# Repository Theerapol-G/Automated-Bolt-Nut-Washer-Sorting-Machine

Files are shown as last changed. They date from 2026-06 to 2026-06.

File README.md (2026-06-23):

# NBN Sorter - Automated Bolt, Nut \& Washer Sorting Machine



> A mechatronics project by students of \*\*Kasetsart University Sriracha Campus\*\*  
> Industrial Engineering Program

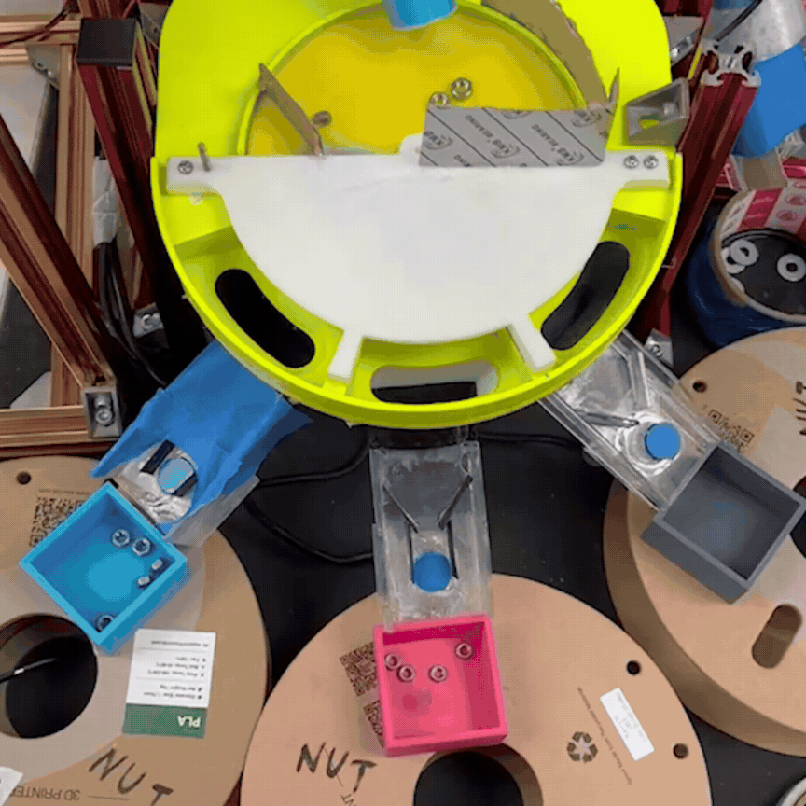
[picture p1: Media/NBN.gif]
NBN


## Project Overview

NBN Sorter is an automated mechanical sorting machine designed to separate mixed hardware fasteners — **bolts, nuts, and washers** — by type and size (M3, M4, M5) without human intervention.

The system uses a combination of gravity-based rail sorting, magnetic conveyance, rotating disk mechanisms, and a real-time TFT dashboard to classify and count each fastener type.

**Input:** Mixed bolts (M3/M4/M5), nuts, and washers poured into the input hopper  
**Output:** Sorted fasteners separated into individual collection bins by size and type

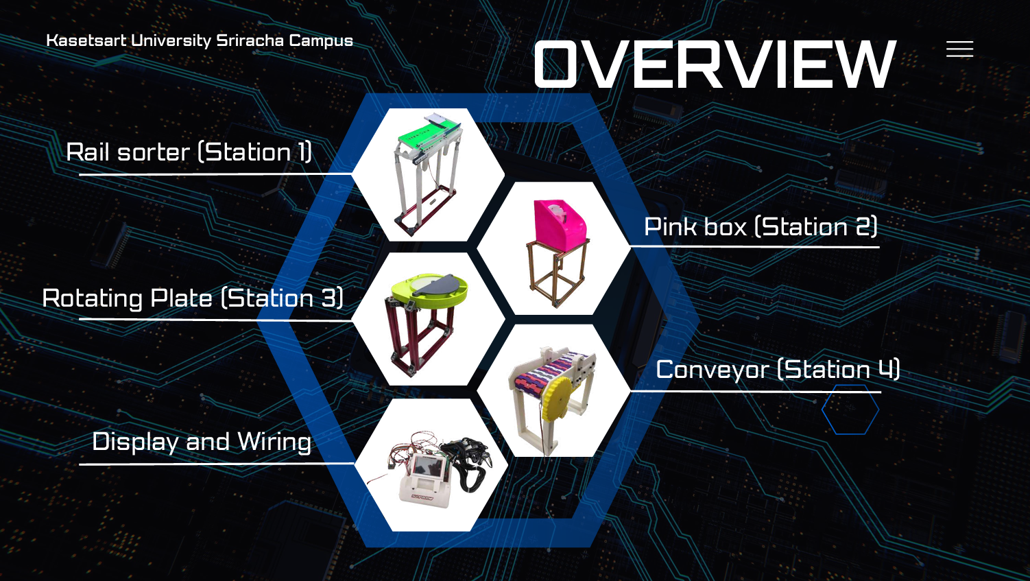
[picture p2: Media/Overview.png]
Overview


## System Architecture 

The machine consists of **4 stations** connected in sequence, plus a display/wiring unit:

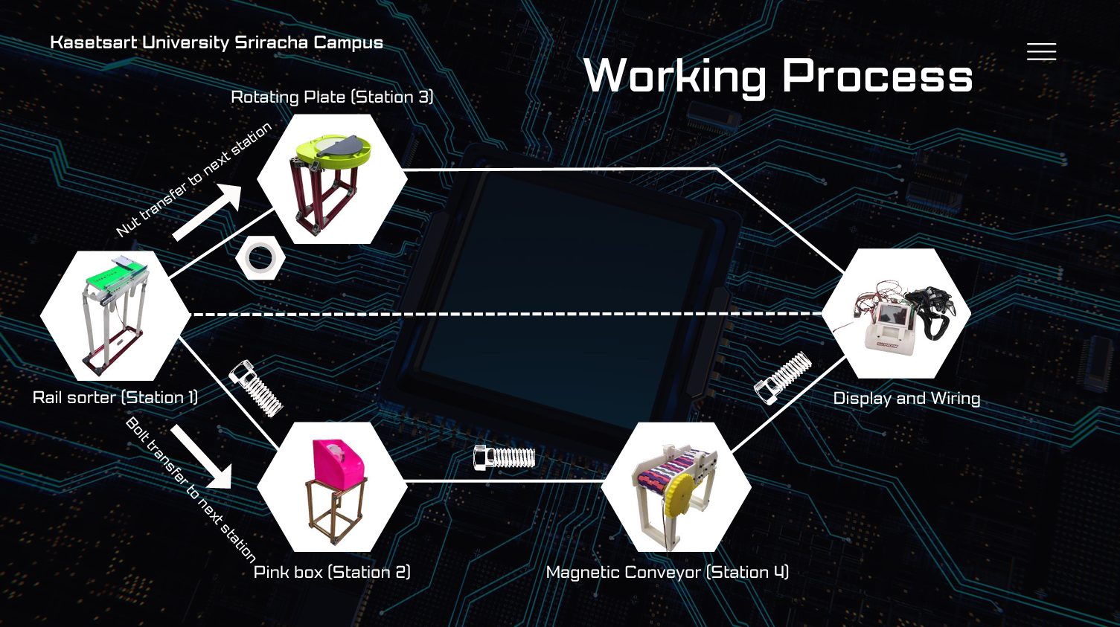
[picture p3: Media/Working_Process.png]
Workflow


## Station Details
## Station 1 - Rail Sorter

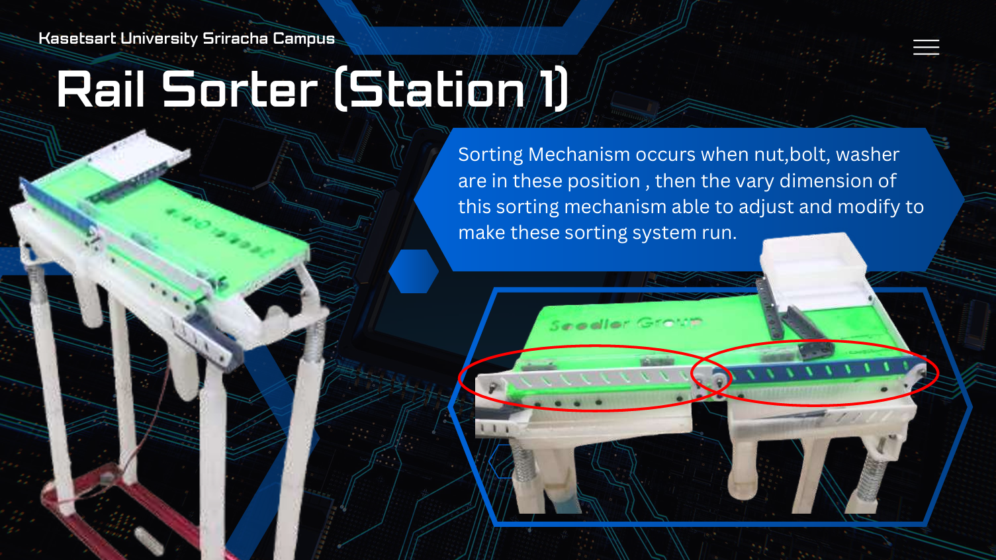
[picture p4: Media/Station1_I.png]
Station 1-1


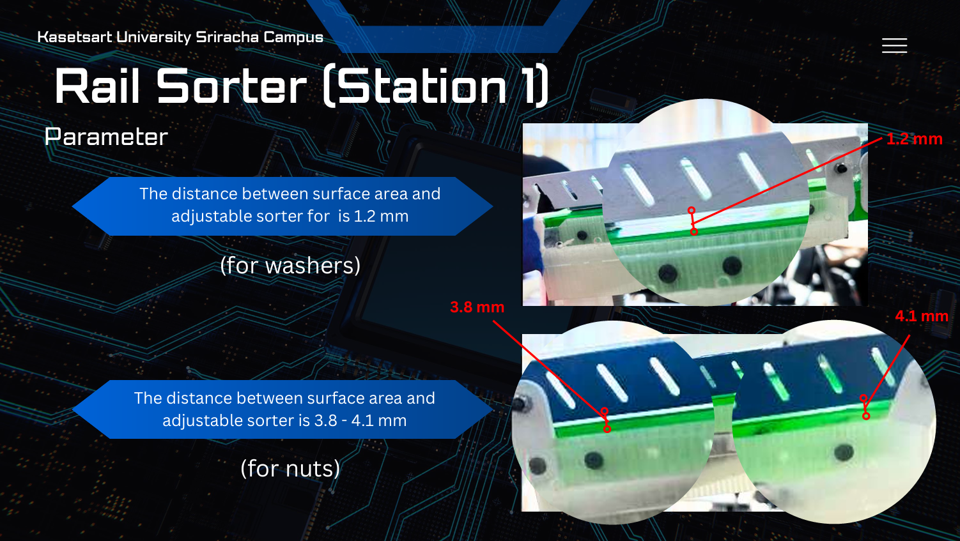
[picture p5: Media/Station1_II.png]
Station 1-2


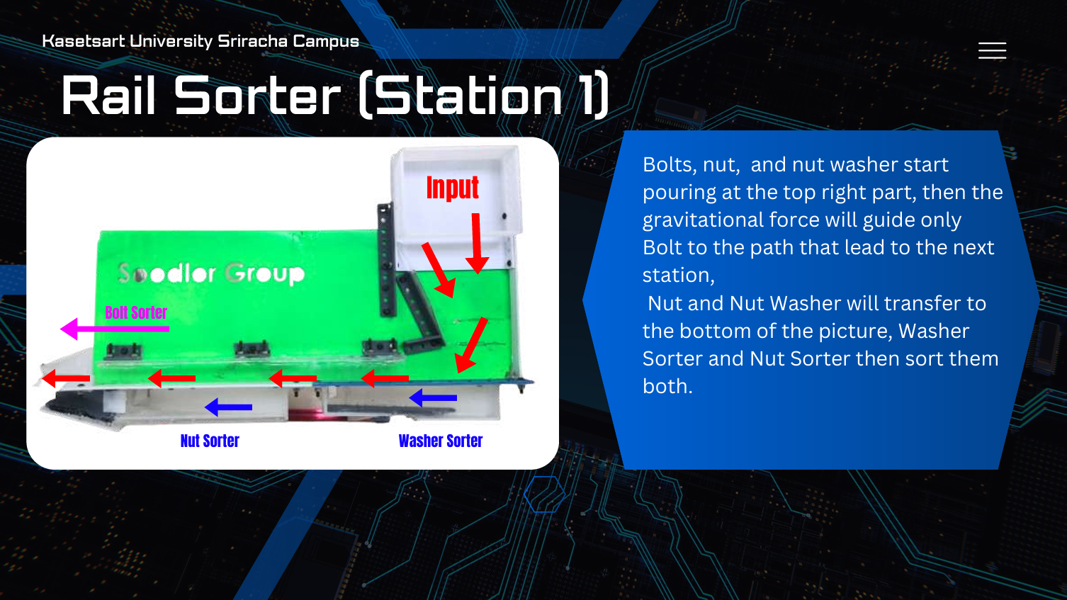
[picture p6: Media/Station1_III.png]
Station 1-3


* Mixed fasteners are poured at the top-right input hopper
* Gravity guides bolts along one path to Station 2
* Nuts and washers slide down to separate sorter rails
* An adjustable gap mechanism separates by thickness:

  * **1.2 mm** gap → washers pass through
  * **3.8–4.1 mm** gap → nuts pass through
* An acrylic cover guide prevents parts from bouncing off due to motor vibration
* Spring-loaded coupling increases incline force to prevent jamming

**Accuracy: 85%** (255/300 over 10 test runs)

## Station 2 - Pink Box (Bolt Feeder)

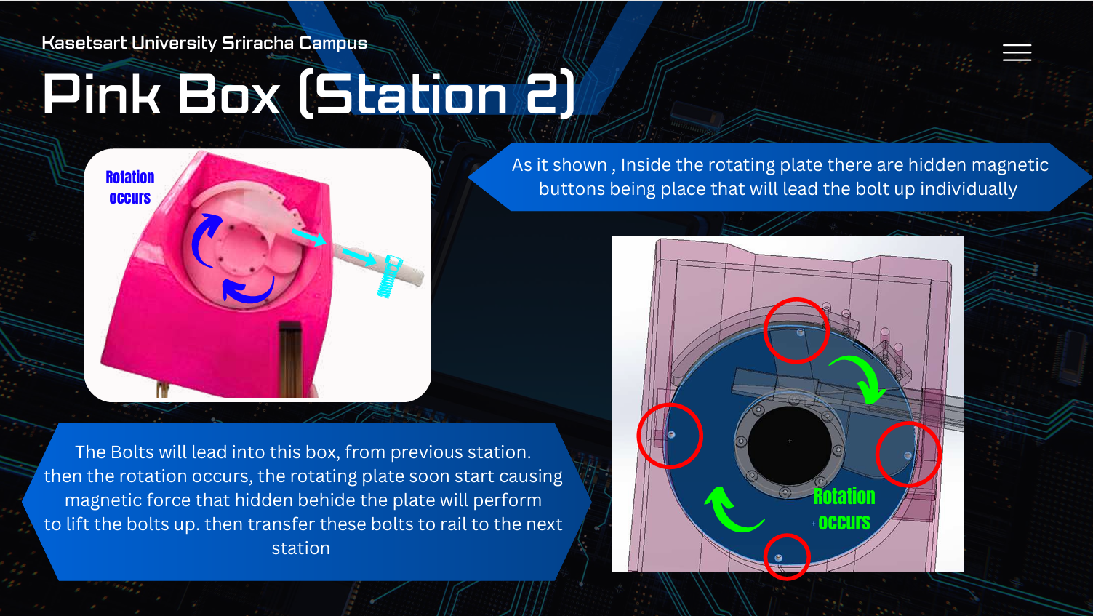
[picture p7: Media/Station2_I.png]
Station 2-1


* Receives bolts from Station 1
* Internal rotating disk with **hidden magnetic buttons** picks up bolts individually
* Bolts are lifted and guided along a rail to Station 4
* Magnetic hole offset: **2.0 mm** (optimal for single-bolt pick-up)
* Guide rail incline was increased to reduce friction-related jamming

**Accuracy: 39%** (39/100 over 10 test runs) — *lowest performing station; main bottleneck*

## Station 3 - Rotating Plate (Nut Sorter)

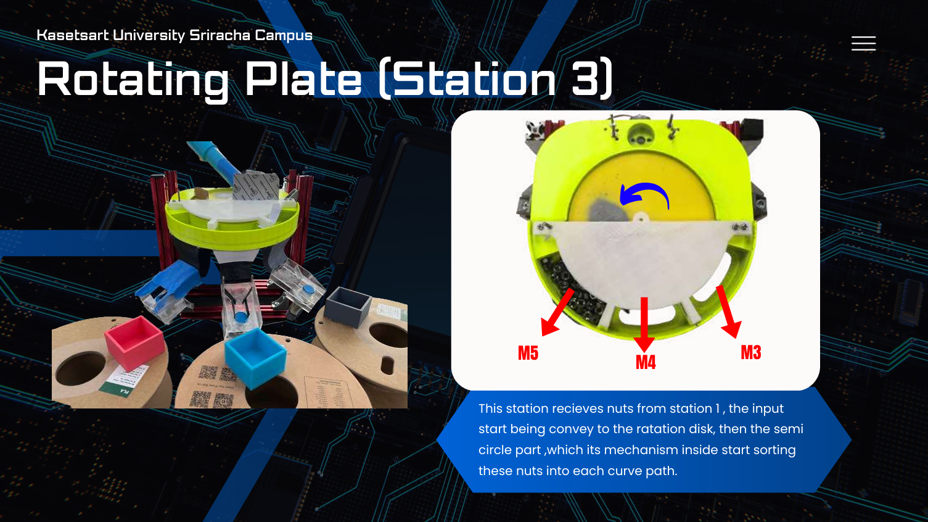
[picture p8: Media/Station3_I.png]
Station 3-1


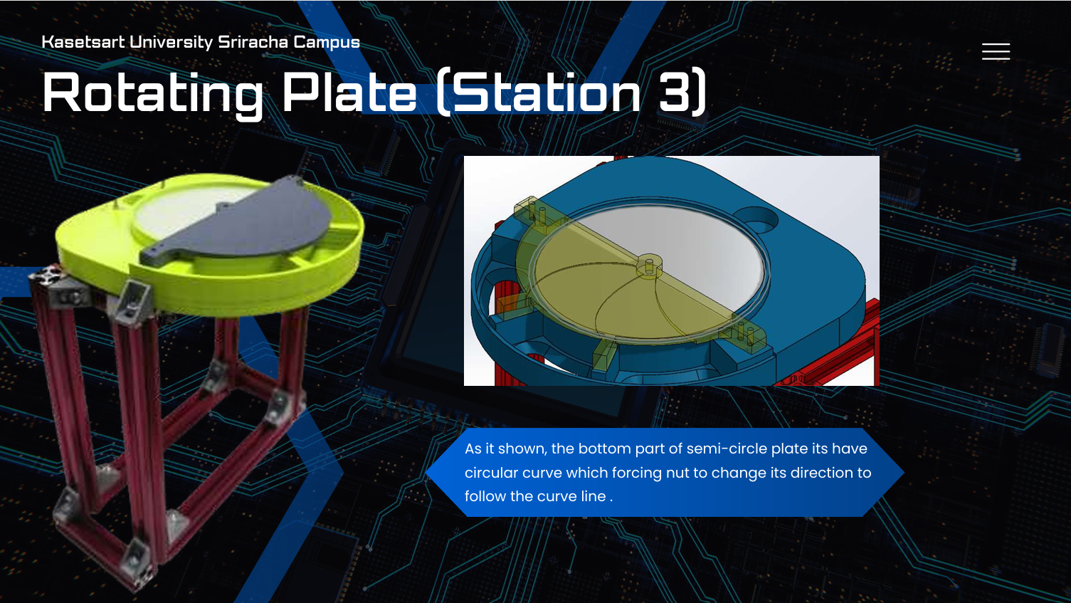
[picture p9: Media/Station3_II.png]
Station 3-2


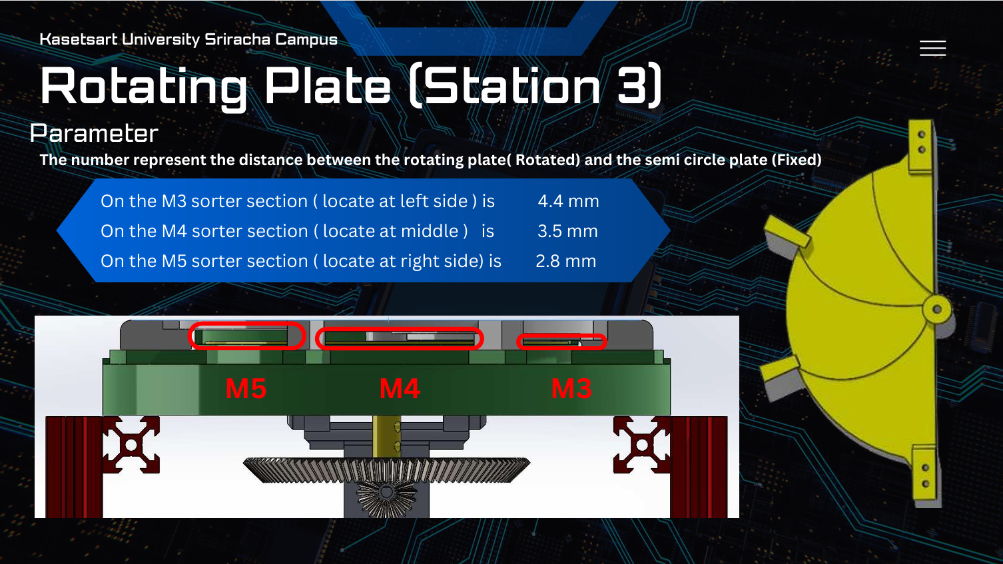
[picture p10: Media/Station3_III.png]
Station 3-3


* Receives nuts from Station 1
* A rotating disk with a fixed semi-circle plate directs nuts into size-based curve paths
* Sorting gap parameters (distance between rotating plate and fixed semi-circle):

  * **M3** section: 4.4 mm
  * **M4** section: 3.5 mm
  * **M5** section: 2.8 mm
* Drive system: bevel gear reduction at **1:4.5 ratio** (replaced original belt-pulley drive)
* Front support added to the semi-circle plate for perpendicular stability

**Accuracy: 97.6%** (117/120 over 10 test runs) — *best performing station*

## Station 4 - Magnetic Conveyor (Bolt Sorter)

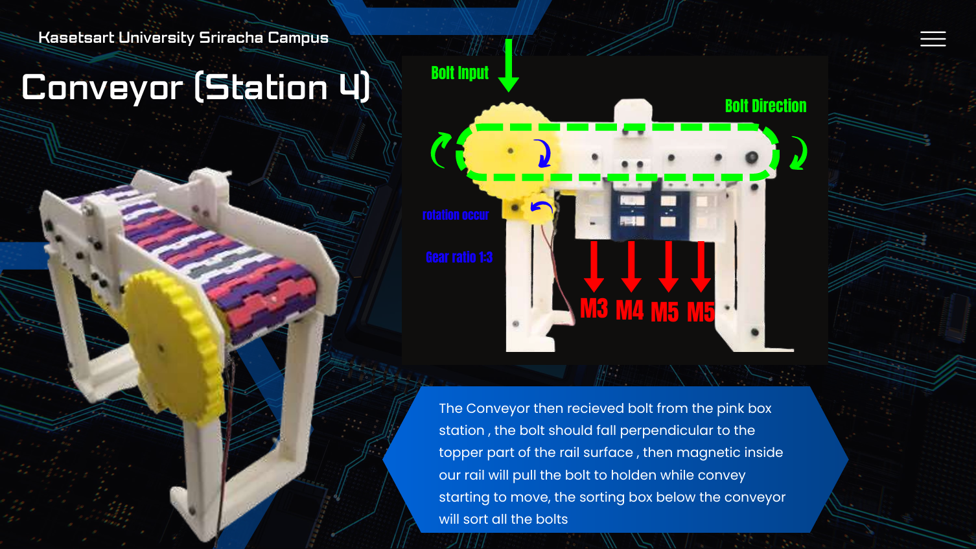
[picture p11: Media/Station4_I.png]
Station 4-1


* Receives bolts from Station 2
* Bolts attach to magnets embedded in the conveyor rail surface
* As the belt moves, bolts drop into M3/M4/M5 collection boxes below
* Wall thickness between bolt and magnet: **1.5 mm offset** (optimal release force)
* Gear ratio: **1:3**
* Conveyor belt uses custom-designed **PLA linkage** (replaced thin metal wire)
* Rail designed from scratch in SolidWorks with embedded magnet holes

**Accuracy: 64%** (64/100 over 10 test runs)

## Display \& Wiring — NBN Dashboard

* Built on **ESP32** with **TFT eSPI** display
* GUI rendered using **LVGL** library
* Displays real-time count of sorted bolts (M3/M4/M5) and nuts/washers
* Serial communication with sensors via **circular buffer**
* Dynamic label updates via `updateUI()` function based on `sensorOut\[]` array

## Overall Results

|Station|Component|Accuracy|
|-|-|-|
|Station 1|Rail Sorter|85%|
|Station 2|Pink Box|39%|
|Station 3|Rotating Plate|**97.6%**|
|Station 4|Magnetic Conveyor|64%|
|**Overall System**|End-to-end (3 runs)|**40.95%**|

### 

## End-to-End Test Summary (3 runs)

|Size|Bolt|Nut|Washer|
|-|-|-|-|
|M3|26.6%|40%|—|
|M4|3.3%|40%|—|
|M5|10%|80%|—|
|OTHER|—|—|90%|
|**Category Total**|**35.71%**|**30%**|**57.14%**|

> Overall system accuracy: \*\*40.95%\*\*

## Known Issues

* **Station 2 (Pink Box)** is the primary bottleneck — magnetic clumping causes multiple bolts to jam together
* **Washer sensor** reads 0% — washers could not be detected reliably in the dashboard
* **Bolt detection** in the dashboard is slow and error-prone
* PLA deformation requires manual filing with vernier caliper to maintain tolerances
* End-to-end accuracy is limited by inter-station transfer reliability

## Design Iterations

The machine went through **6 design versions** before reaching the final build, iterating on:

* Structural layout and station arrangement
* Drive systems (belt-pulley → bevel gear reduction)
* Conveyor belt material (metal wire → PLA linkage)
* Sorting gap dimensions (empirically tested)

## Team Member

* Chanaprachpakorn Ngernmo
* Theerapol Guanmuangtai
* Thanakrit Wongkha
* Warut Tongrung
* Norawich Lorttrakanont
* Kunasin Laysak
* Danuphat Parnpradit
* Thanakon Chaichana
* Jerich Brylle Sison
* Sajakorn Chutikarnmongkol

## Institution

**Kasetsart University Sriracha Campus**  
Industrial Engineering Program

*This project was developed as part of an academic engineering design course.*
**Full Demonstration Video**: 🔗 **[Watch on YouTube](https://youtu.be/BTTlB-tEGTM?si=GIfPtlQIp4Oagcnz)**

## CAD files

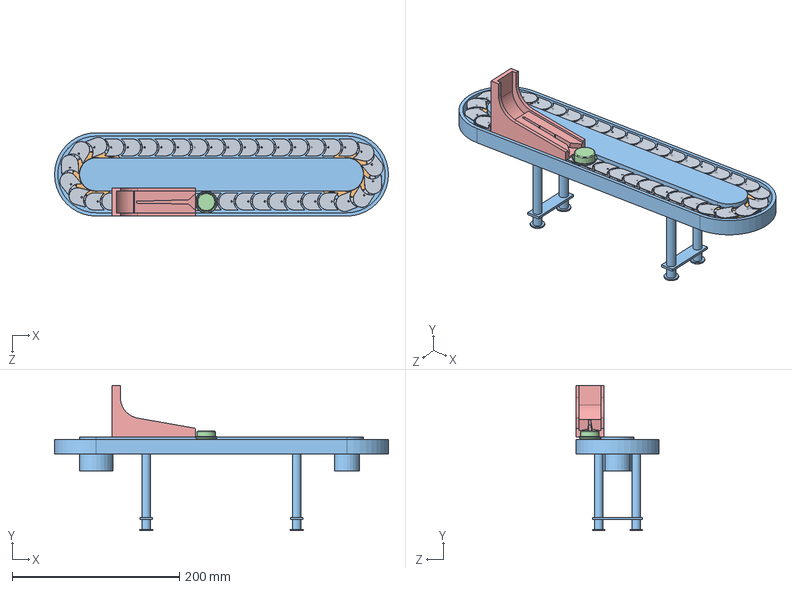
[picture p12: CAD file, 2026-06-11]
3D/Project_sudlorsssss/Assem2.SLDASM
399.7 x 174.0 x 99.9 mm
link x 40
spocket x 2
TABLE FRAME
SERV
Sushin A

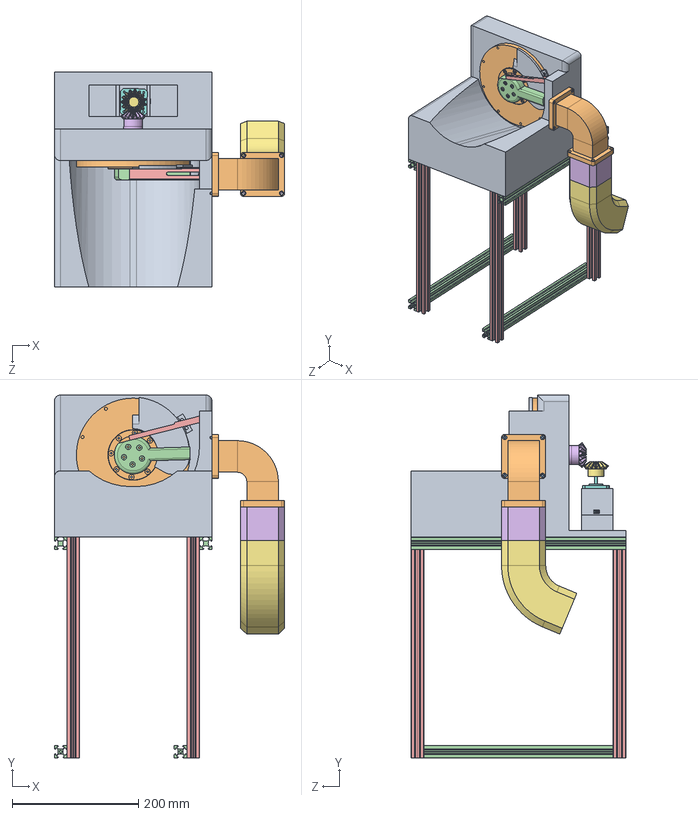
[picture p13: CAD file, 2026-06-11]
3D/Project_sudlorsssss/Project_sudlor/AssemArt.SLDASM
365.0 x 575.0 x 340.0 mm
box bolt sort
Art1
Art2
Art3
Art4
Art6
straight bevel pinion_iso
NEMA17_STEPPER
Art4-ford
socket head cap screw_iso x 4
rotate heads
asd

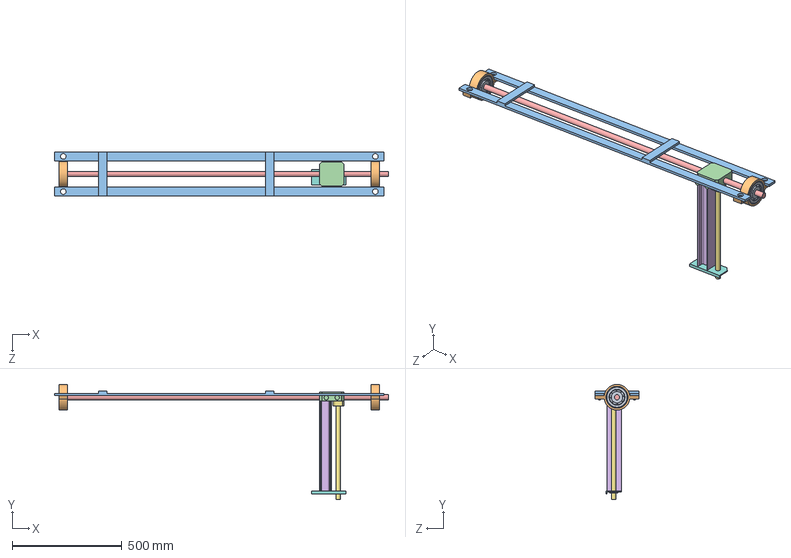
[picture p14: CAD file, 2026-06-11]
3D/Project_sudlorsssss/Project_sudlor/Upper/TheJapaneseGirlThatIMet1TimeAndWillNeverHasChanceToMeetHerAgain.SLDASM
1520.0 x 524.5 x 200.0 mm
Bearing x 2
clamp x 4
main frame v2
vasi v2
dildo1350mm
alu_profile
rod430mm
new_alu_plate_up

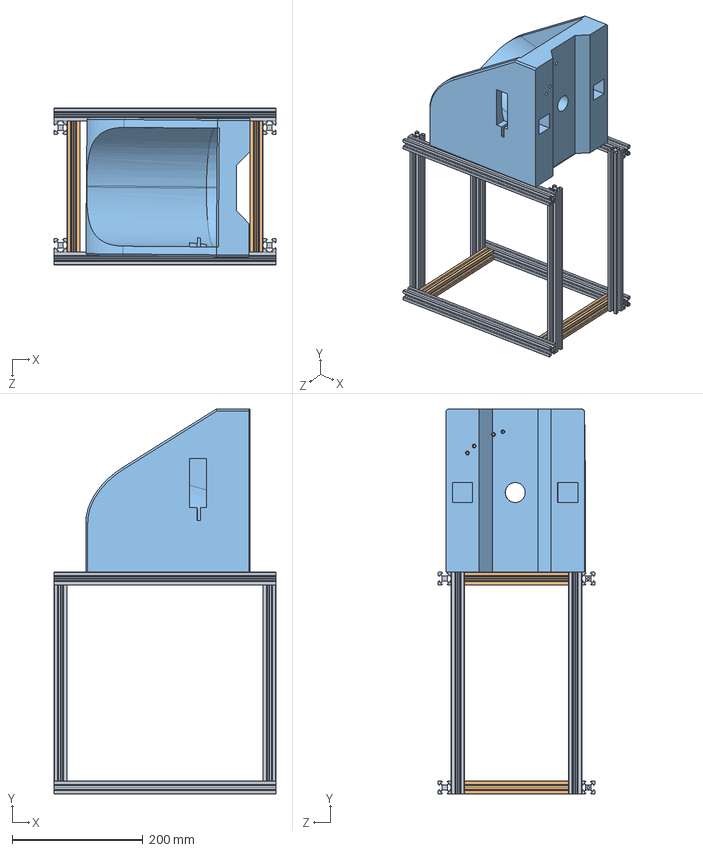
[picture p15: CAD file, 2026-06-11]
3D/Project_sudlorsssss/Project_sudlor/Assemforconveyor.SLDASM
340.0 x 590.0 x 240.0 mm
150mm x 4
ford

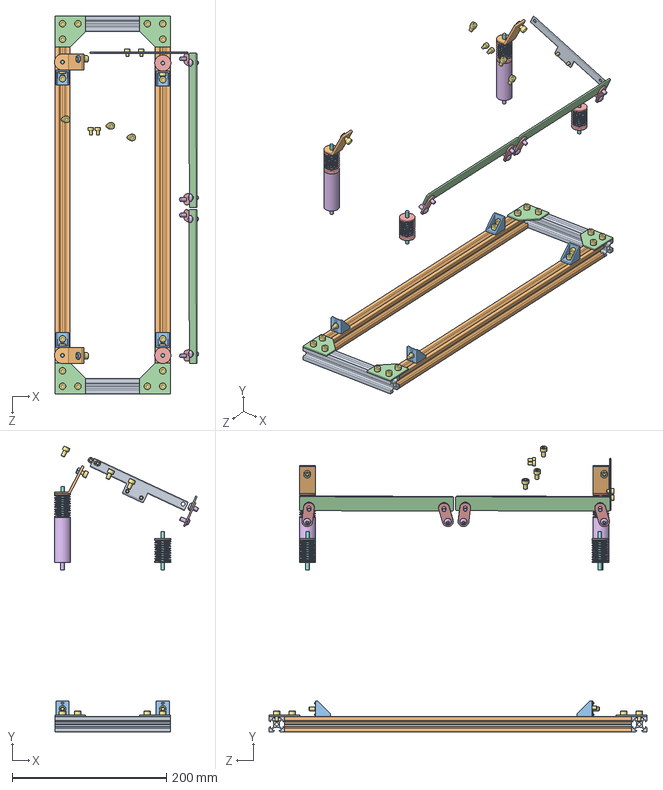
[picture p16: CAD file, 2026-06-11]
3D/Project_sudlorsssss/Project_sudlor/Part1/assem_part_s.SLDASM
186.9 x 370.7 x 490.0 mm
0.15m x 2
0.45m x 2
lock x 4
corner plate x 4
spring x 4
upspring x 2
socket head cap screw_iso x 29
pole_spring x 4
block
L_base_back x 2
hex nut gradec_iso x 2
sort x 2
lock_sort x 4
socket button head screw_iso x 8

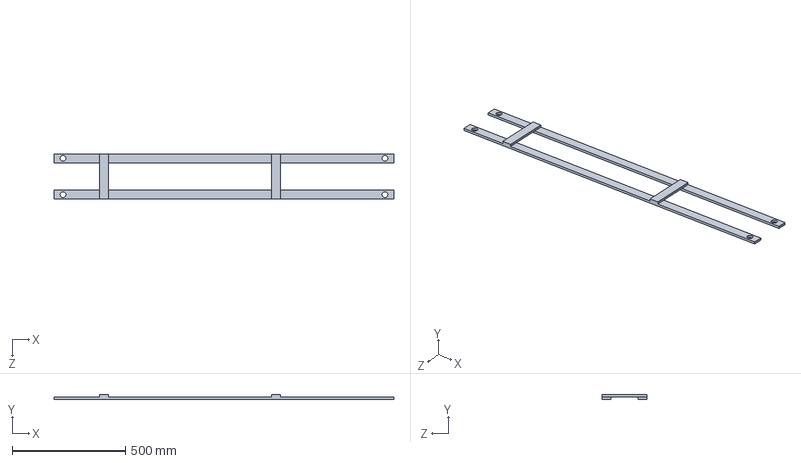
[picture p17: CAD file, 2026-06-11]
3D/Project_sudlorsssss/Project_sudlor/Upper/main frame v2.SLDPRT
1500.0 x 20.0 x 200.0 mm

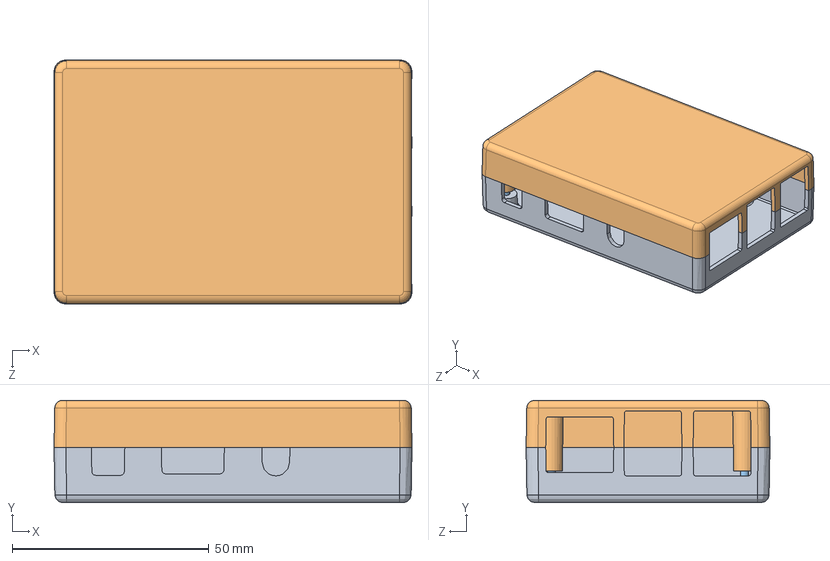
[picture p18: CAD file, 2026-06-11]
3D/Project_sudlorsssss/Project_sudlor/raspberry-pi-27.snapshot.7/Raspberry Pi Enclosure - 10MSW.SLDASM
91.0 x 26.0 x 62.0 mm
Enclosure Base
Enclosure Top
pan cross head_am x 4

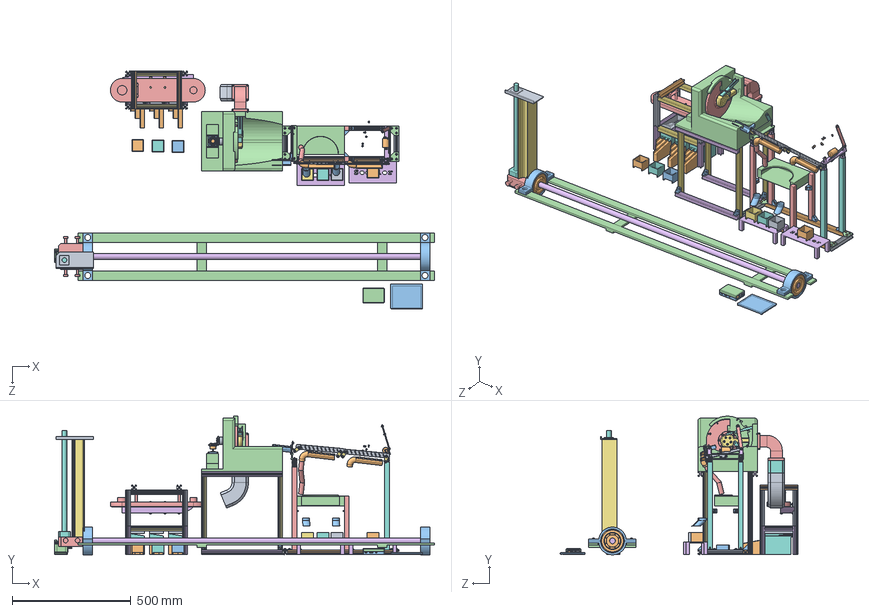
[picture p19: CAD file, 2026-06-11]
3D/Project_sudlorsssss/Project_sudlor/AiMaSiKon_New_newna.SLDASM
1600.0 x 584.1 x 1000.0 mm
0.15m2 x 2
0.45m x 2
lock x 14
corner plate x 4
wood_pole2 x 4
spring x 4
socket head cap screw_iso x 22
wood_pole x 2
block
socket button head screw_iso x 40
pole_spring x 4
base_slide5
lock6
base_slide4
lock_sort x 5
Base_sp
sort x 2
swept x 2
Bolt_slide_1
Covernew
tor_tir
small_table x 2
box_y
box_p x 2
box_r
box_g x 2
to x 2
box bolt sort
Art1
Art2
Art3
Art4
Art6
straight bevel pinion_iso
NEMA17_STEPPER
Art4-ford
rotate heads
asd
Bearing x 2
clamp x 4
main frame v2
vasi v2
dildo1350mm
alu_profile
rod430mm
new_alu_plate_up
dc vibrator
AA057VG02.step
ML23HS8P_motor_only
ML23HS8P_SHAFT
Mainboard2^Copy of RaspberryPi(2)_Raspberry Pi Enclosure - 10MSW
GPIO^Copy of RaspberryPi(2)_Raspberry Pi Enclosure - 10MSW
Processor^Copy of RaspberryPi(2)_Raspberry Pi Enclosure - 10MSW
GPU^Copy of RaspberryPi(2)_Raspberry Pi Enclosure - 10MSW
CameraAssembly^Copy of RaspberryPi(2)_Raspberry Pi Enclosure - 10MSW x 2
HDMI^Copy of RaspberryPi(2)_Raspberry Pi Enclosure - 10MSW
RAM^Copy of RaspberryPi(2)_Raspberry Pi Enclosure - 10MSW
Audio^Copy of RaspberryPi(2)_Raspberry Pi Enclosure - 10MSW
MicroSDSocket^Copy of RaspberryPi(2)_Raspberry Pi Enclosure - 10MSW
MicroSD^Copy of RaspberryPi(2)_Raspberry Pi Enclosure - 10MSW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

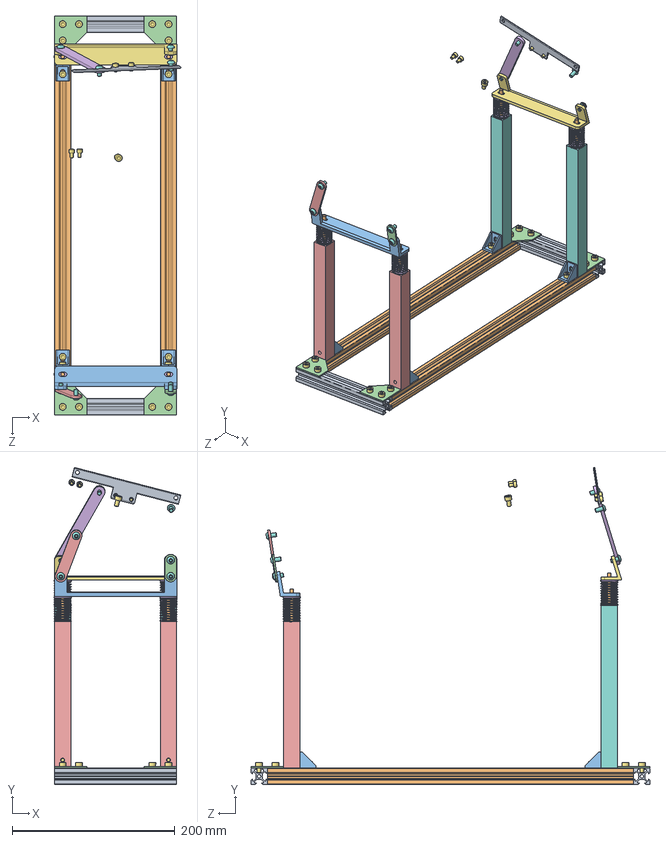
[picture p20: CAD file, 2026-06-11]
3D/Project_sudlorsssss/Project_sudlor/Part1/assem_part_sss.SLDASM
155.5 x 389.3 x 490.0 mm
0.15m x 2
0.45m x 2
lock x 4
corner plate x 4
wood_pole2 x 2
spring x 4
socket head cap screw_iso x 23
wood_pole x 2
block
pole_spring x 4
base_slide5
lock_sort
Base_sp
lock6
base_slide4
socket button head screw_iso x 8

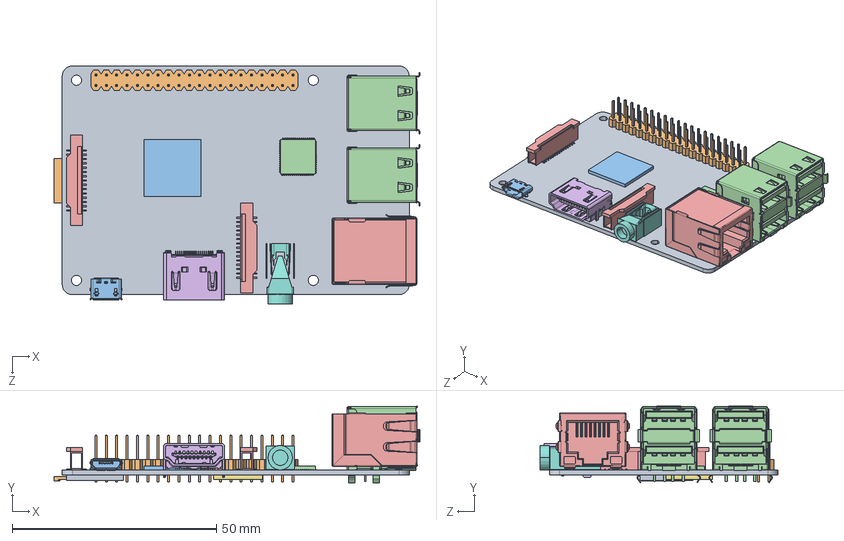
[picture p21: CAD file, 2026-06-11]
3D/Project_sudlorsssss/Project_sudlor/raspberry-pi-27.snapshot.7/RaspberryPi.SLDASM
89.6 x 18.7 x 58.3 mm
Mainboard2^RaspberryPi(2)_RaspberryPi
GPIO^RaspberryPi(2)_RaspberryPi
Processor^RaspberryPi(2)_RaspberryPi
GPU^RaspberryPi(2)_RaspberryPi
CameraAssembly^RaspberryPi(2)_RaspberryPi x 2
HDMI^RaspberryPi(2)_RaspberryPi
RAM^RaspberryPi(2)_RaspberryPi
Audio^RaspberryPi(2)_RaspberryPi
MicroSDSocket^RaspberryPi(2)_RaspberryPi
MicroSD^RaspberryPi(2)_RaspberryPi
micro USB2^RaspberryPi(2)_RaspberryPi
usb double^RaspberryPi(2)_RaspberryPi x 2
RJ45-LED^RaspberryPi(2)_RaspberryPi

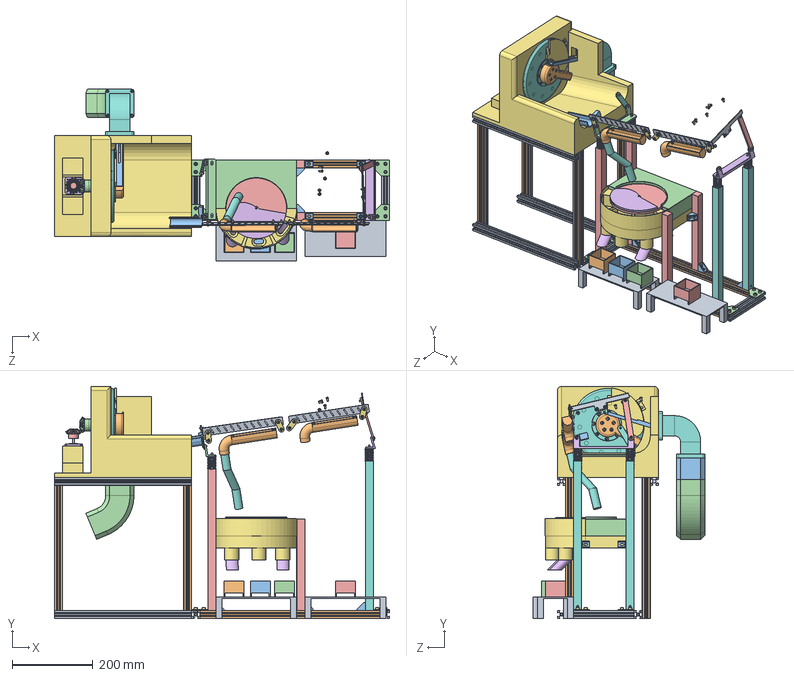
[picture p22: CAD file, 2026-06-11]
3D/Project_sudlorsssss/Project_sudlor/AiMaSiKon_New.SLDASM
830.0 x 575.0 x 425.0 mm
0.15m2 x 2
0.45m x 2
lock x 10
corner plate x 4
wood_pole2 x 4
spring x 4
socket head cap screw_iso x 22
wood_pole x 2
block
socket button head screw_iso x 28
pole_spring x 4
base_slide5
lock6
base_slide4
lock_sort x 5
Base_sp
sort x 2
swept x 2
Bolt_slide_1
Covernew
turntablenew
guidenew2
collectornew
tor_tir
small_table x 2
box_y
box_p
box_r
box_g
to x 2
box bolt sort
Art1
Art2
Art3
Art4
Art6
straight bevel pinion_iso
NEMA17_STEPPER
Art5
rotate heads
asd

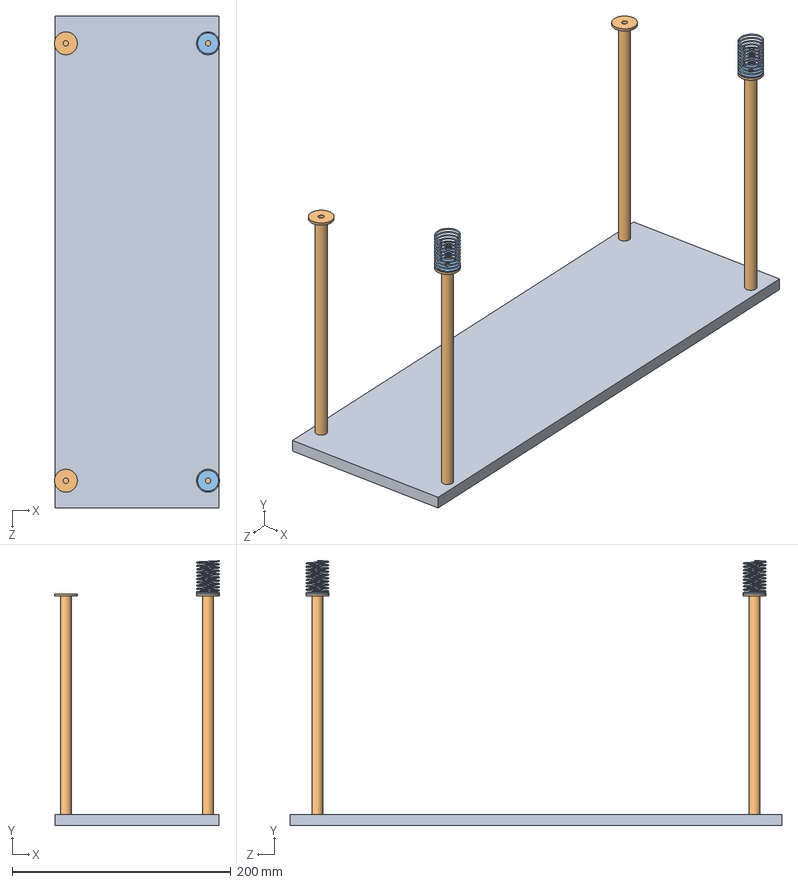
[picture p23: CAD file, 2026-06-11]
3D/Project_sudlorsssss/Project_sudlor/Part1/assem_test.SLDASM
151.0 x 242.5 x 450.0 mm
base
pole x 4
spring x 2

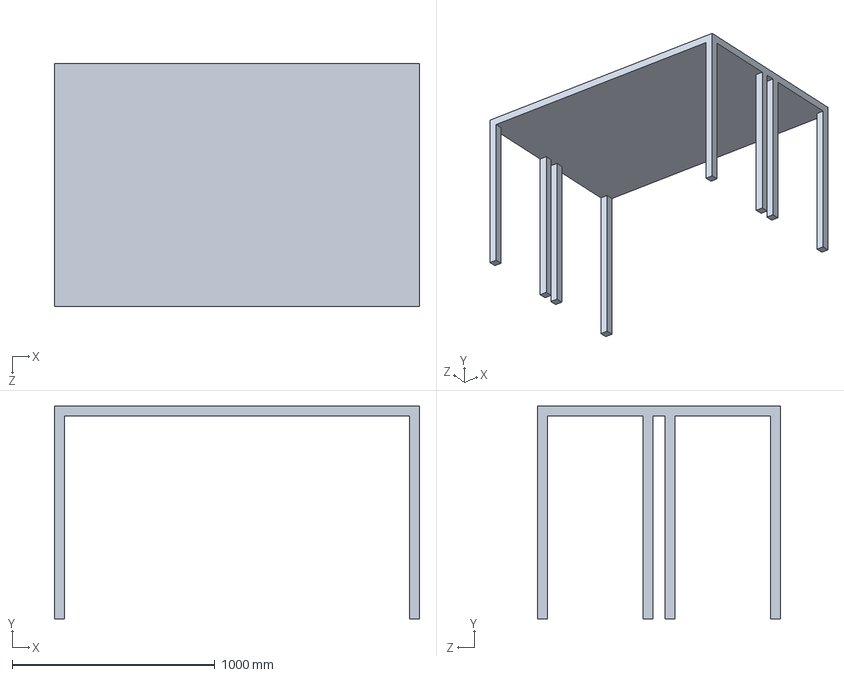
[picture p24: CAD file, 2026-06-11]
3D/Project_sudlorsssss/Project_sudlor/Part1/Assem1.SLDASM
1800.0 x 1050.0 x 1200.0 mm

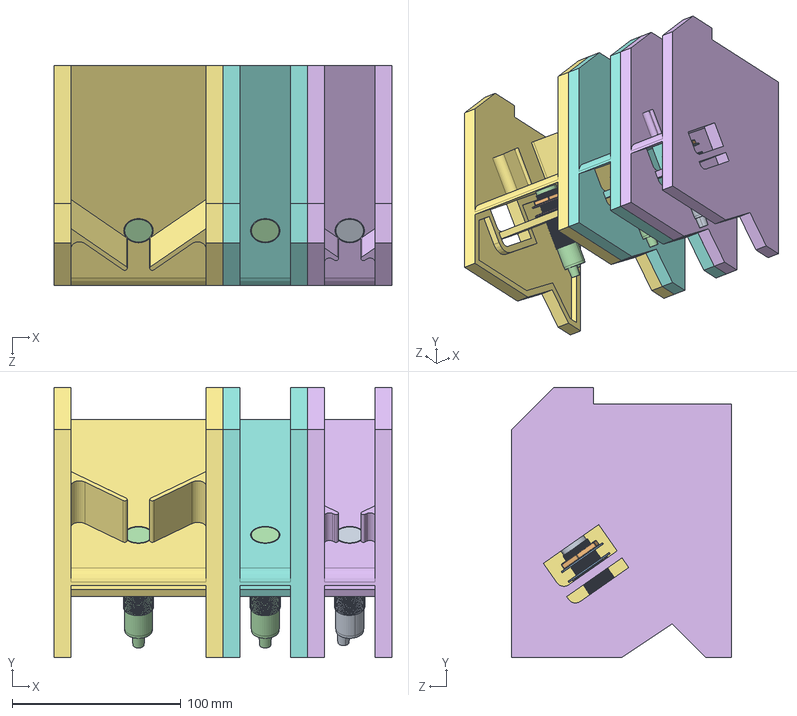
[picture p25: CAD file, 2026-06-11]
3D/Project_sudlorsssss/Project_sudlor/SORTER_BELOW.SLDASM
200.0 x 160.0 x 130.0 mm
Sensor.step.STEP
Nut.step.STEP x 6
Lock Washer.step.STEP x 2
Sensor_1.step.STEP x 2
Lock Washer_1.step.STEP x 4
holder for m3.STEP
holder for m5.STEP
holder for bolt.STEP

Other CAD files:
3D/Project_sudlorsssss/Project_sudlor/raspberry-pi-27.snapshot.7/CameraAssembly.sldprt
3D/Project_sudlorsssss/Project_sudlor/Part1/assem_rail.SLDASM
3D/Project_sudlorsssss/Project_sudlor/gear_d.SLDASM
3D/Project_sudlorsssss/Project_sudlor/Part1/assem_part_show.SLDASM
3D/Project_sudlorsssss/Art4-ford.STL
3D/Project_sudlorsssss/Project_Assem/Project Assem/Rail_sorter.STEP
3D/Project_sudlorsssss/Project_Assem/Project Assem/asem_for_nut.STEP
3D/Project_sudlorsssss/Project_sudlor/AiMaSiKon.SLDASM
3D/Project_sudlorsssss/Project_sudlor/AiMaSiKon.STEP
3D/Project_sudlorsssss/Project_sudlor/Assem1.SLDASM
3D/Project_sudlorsssss/Project_sudlor/Part1/+motor.SLDPRT
3D/Project_sudlorsssss/Project_sudlor/Part1/+motor.STL
3D/Project_sudlorsssss/Project_sudlor/Part1/Base_sp.SLDPRT
3D/Project_sudlorsssss/Project_sudlor/Part1/Bolt_slide_1.SLDPRT
3D/Project_sudlorsssss/Project_sudlor/Part1/L_base.SLDPRT
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

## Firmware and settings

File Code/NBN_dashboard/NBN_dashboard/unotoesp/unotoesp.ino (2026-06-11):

#include <freertos/FreeRTOS.h>
#include <freertos/task.h>

#define NUM_SENSORS 13
int sensorPins[NUM_SENSORS] = {34, 35, 32, 33, 25, 26, 27, 14, 12, 13, 4, 15, 2};
boolean sensorStatus[NUM_SENSORS];
boolean prevSensorStatus[NUM_SENSORS];
int sensorCount[NUM_SENSORS] = {0};

// Function to read analog values and update sensor status
void readSensors(void* pvParameters) {
    while (1) {
        for (int i = 0; i < NUM_SENSORS; i++) {
            int sensorValue = analogRead(sensorPins[i]);
            if (sensorValue < 700) {
                sensorStatus[i] = true;
                if (!prevSensorStatus[i]) {
                    sensorCount[i]++;
                }
            } else {
                sensorStatus[i] = false;
            }
        }
        vTaskDelay(10 / portTICK_PERIOD_MS); // Adjust delay as needed
    }
}

// Function to process sensor data and print counts
void processSensorData(void* pvParameters) {
    while (1) {
        bool statusChanged = false;
        for (int i = 0; i < NUM_SENSORS; i++) {
            if (sensorStatus[i] != prevSensorStatus[i]) {
                statusChanged = true;
                break;
            }
        }

        if (statusChanged) {
            Serial.print("{");
            for (int i = 0; i < NUM_SENSORS; i++) {
                Serial.print(sensorCount[i]);
                if (i < NUM_SENSORS - 1) {
                    Serial.print(",");
                }
            }
            Serial.println("}");

            for (int i = 0; i < NUM_SENSORS; i++) {
                prevSensorStatus[i] = sensorStatus[i];
            }
        }
        vTaskDelay(10 / portTICK_PERIOD_MS); // Adjust delay as needed
    }
}

void setup() {
    Serial.begin(115200);

    // Initialize sensor pins
    for (int i = 0; i < NUM_SENSORS; i++) {
        pinMode(sensorPins[i], INPUT);
        sensorStatus[i] = false;
        prevSensorStatus[i] = false;
    }

    // Create tasks and assign them to cores
    xTaskCreatePinnedToCore(readSensors, "Read Sensors", 4096, NULL, 1, NULL, 0);
    xTaskCreatePinnedToCore(processSensorData, "Process Data", 4096, NULL, 1, NULL, 1);
}

void loop() {
    // Nothing to do here, tasks run on separate cores
}

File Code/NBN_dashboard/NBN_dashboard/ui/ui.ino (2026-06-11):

#include <lvgl.h>
#include <TFT_eSPI.h>
#include <ui.h>
#include "config.h"
#include <CircularBuffer.h> // Include the circular buffer library
const int BUFFER_SIZE = 256; // Adjust the size as needed
CircularBuffer<char, BUFFER_SIZE> serialBuffer;

#define NUM_SENSORS 13
int sensorOut[NUM_SENSORS];
static const uint16_t screenWidth = 480;
static const uint16_t screenHeight = 320;

static lv_disp_draw_buf_t draw_buf;
static lv_color_t buf[screenWidth * screenHeight / 10];

TFT_eSPI tft = TFT_eSPI(screenWidth, screenHeight); /* TFT instance */

#if LV_USE_LOG != 0
/* Serial debugging */
void my_print(const char * buf)
{
    Serial.printf(buf);
    Serial.flush();
}
#endif
/* Display flushing */
void my_disp_flush( lv_disp_drv_t *disp, const lv_area_t *area, lv_color_t *color_p )
{
    uint32_t w = ( area->x2 - area->x1 + 1 );
    uint32_t h = ( area->y2 - area->y1 + 1 );

    tft.startWrite();
    tft.setAddrWindow( area->x1, area->y1, w, h );
    tft.pushColors( ( uint16_t * )&color_p->full, w * h, true );
    tft.endWrite();

    lv_disp_flush_ready( disp );
}
lv_obj_t* ui_Label11 = NULL;
lv_obj_t* ui_Label14 = NULL;
lv_obj_t* ui_Label1 = NULL;
lv_obj_t* ui_Label12 = NULL;
lv_obj_t* ui_Label15 = NULL;
lv_obj_t* ui_Label16 = NULL;
lv_obj_t* ui_Label17 = NULL;
lv_obj_t* ui_Label18 = NULL;
lv_obj_t* ui_Label19 = NULL;
lv_obj_t* ui_Label7 = NULL;
lv_obj_t* ui_Label13 = NULL;
lv_obj_t* ui_Label20 = NULL;
lv_obj_t* ui_Label21 = NULL;

// Update LVGL UI with sensor data
void updateUI(int sensorOut[]) {
  // Delete existing labels
  if (ui_Label11 != NULL) {
    lv_obj_del(ui_Label11);
    ui_Label11 = NULL;
  }
  if (ui_Label14 != NULL) {
    lv_obj_del(ui_Label14);
    ui_Label14 = NULL;
  }
  if (ui_Label1 != NULL) {
    lv_obj_del(ui_Label1);
    ui_Label1 = NULL;
  }
  if (ui_Label12 != NULL) {
    lv_obj_del(ui_Label12);
    ui_Label12 = NULL;
  }
  if (ui_Label15 != NULL) {
    lv_obj_del(ui_Label15);
    ui_Label15 = NULL;
  }
  if (ui_Label16 != NULL) {
    lv_obj_del(ui_Label16);
    ui_Label16 = NULL;
  }
  if (ui_Label17 != NULL) {
    lv_obj_del(ui_Label17);
    ui_Label17 = NULL;
  }
  if (ui_Label18 != NULL) {
    lv_obj_del(ui_Label18);
    ui_Label18 = NULL;
  }
  if (ui_Label19 != NULL) {
    lv_obj_del(ui_Label19);
    ui_Label19 = NULL;
  }
  if (ui_Label7 != NULL) {
    lv_obj_del(ui_Label7);
    ui_Label7 = NULL;
  }
  if (ui_Label13 != NULL) {
    lv_obj_del(ui_Label13);
    ui_Label13 = NULL;
  }
  if (ui_Label20 != NULL) {
    lv_obj_del(ui_Label20);
    ui_Label20 = NULL;
  }
  if (ui_Label21 != NULL) {
    lv_obj_del(ui_Label21);
    ui_Label21 = NULL;
  }

  // Create a new label object
    ui_Label11 = lv_label_create(lv_scr_act());
    lv_obj_set_width(ui_Label11, LV_SIZE_CONTENT);
    lv_obj_set_height(ui_Label11, LV_SIZE_CONTENT);
    lv_obj_set_x(ui_Label11, 40);
    lv_obj_set_y(ui_Label11, -62);
    lv_obj_set_align(ui_Label11, LV_ALIGN_CENTER);
    char buffer1[3];
    snprintf(buffer1, sizeof(buffer1), "%d", sensorOut[0]);
    lv_label_set_text(ui_Label11, buffer1);
    lv_obj_set_style_text_color(ui_Label11, lv_color_hex(0x28FF49), LV_PART_MAIN | LV_STATE_DEFAULT);
    lv_obj_set_style_text_opa(ui_Label11, 255, LV_PART_MAIN | LV_STATE_DEFAULT);
    lv_obj_set_style_text_font(ui_Label11, &lv_font_montserrat_16, LV_PART_MAIN | LV_STATE_DEFAULT);
    
    // Repeat the above code for other sensor labels if needed
    ui_Label14 = lv_label_create(lv_scr_act());
    lv_obj_set_width(ui_Label14, LV_SIZE_CONTENT);
    lv_obj_set_height(ui_Label14, LV_SIZE_CONTENT);
    lv_obj_set_x(ui_Label14, 40);
    lv_obj_set_y(ui_Label14, -33);
    lv_obj_set_align(ui_Label14, LV_ALIGN_CENTER);

    // Update the label text with the sensor value
    char buffer2[3];
    snprintf(buffer2, sizeof(buffer2), "%d", sensorOut[1]);
    lv_label_set_text(ui_Label14, buffer2);
    lv_obj_set_style_text_color(ui_Label14, lv_color_hex(0x28FF49), LV_PART_MAIN | LV_STATE_DEFAULT);
    lv_obj_set_style_text_opa(ui_Label14, 255, LV_PART_MAIN | LV_STATE_DEFAULT);
    lv_obj_set_style_text_font(ui_Label14, &lv_font_montserrat_16, LV_PART_MAIN | LV_STATE_DEFAULT);
 
 
     ui_Label1 = lv_label_create(lv_scr_act());
    lv_obj_set_width(ui_Label1, LV_SIZE_CONTENT);   /// 1
    lv_obj_set_height(ui_Label1, LV_SIZE_CONTENT);    /// 1
    lv_obj_set_x(ui_Label1, 80);
    lv_obj_set_y(ui_Label1, -62);
    lv_obj_set_align(ui_Label1, LV_ALIGN_CENTER);
    char buffer3[3];
    snprintf(buffer3, sizeof(buffer3), "%d", sensorOut[2]);
     lv_label_set_text(ui_Label1, buffer3);
    lv_obj_set_style_text_color(ui_Label1, lv_color_hex(0x28FF49), LV_PART_MAIN | LV_STATE_DEFAULT);
    lv_obj_set_style_text_opa(ui_Label1, 255, LV_PART_MAIN | LV_STATE_DEFAULT);
    lv_obj_set_style_text_font(ui_Label1, &lv_font_montserrat_16, LV_PART_MAIN | LV_STATE_DEFAULT);
 
 
    ui_Label12 = lv_label_create(ui_Screen1);
    lv_obj_set_width(ui_Label12, LV_SIZE_CONTENT);   /// 1
    lv_obj_set_height(ui_Label12, LV_SIZE_CONTENT);    /// 1
    lv_obj_set_x(ui_Label12, 120);
    lv_obj_set_y(ui_Label12, -62);
    lv_obj_set_align(ui_Label12, LV_ALIGN_CENTER);
    char buffer4[3]; // Assuming the maximum value can fit in 10 characters
    snprintf(buffer4, sizeof(buffer4), "%d", sensorOut[3]);
    lv_label_set_text(ui_Label12, buffer4);
    lv_obj_set_style_text_color(ui_Label12, lv_color_hex(0x28FF49), LV_PART_MAIN | LV_STATE_DEFAULT);
    lv_obj_set_style_text_opa(ui_Label12, 255, LV_PART_MAIN | LV_STATE_DEFAULT);
    lv_obj_set_style_text_font(ui_Label12, &lv_font_montserrat_16, LV_PART_MAIN | LV_STATE_DEFAULT);
 
    ui_Label15 = lv_label_create(ui_Screen1);
    lv_obj_set_width(ui_Label15, LV_SIZE_CONTENT);   /// 1
    lv_obj_set_height(ui_Label15, LV_SIZE_CONTENT);    /// 1
    lv_obj_set_x(ui_Label15, 80);
    lv_obj_set_y(ui_Label15, -34);
    lv_obj_set_align(ui_Label15, LV_ALIGN_CENTER);
    char buffer5[3]; // Assuming the maximum value can fit in 10 characters
    snprintf(buffer5, sizeof(buffer5), "%d", sensorOut[4]);
    lv_label_set_text(ui_Label15, buffer5);
    lv_obj_set_style_text_color(ui_Label15, lv_color_hex(0x28FF49), LV_PART_MAIN | LV_STATE_DEFAULT);
    lv_obj_set_style_text_opa(ui_Label15, 255, LV_PART_MAIN | LV_STATE_DEFAULT);
    lv_obj_set_style_text_font(ui_Label15, &lv_font_montserrat_16, LV_PART_MAIN | LV_STATE_DEFAULT);
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
